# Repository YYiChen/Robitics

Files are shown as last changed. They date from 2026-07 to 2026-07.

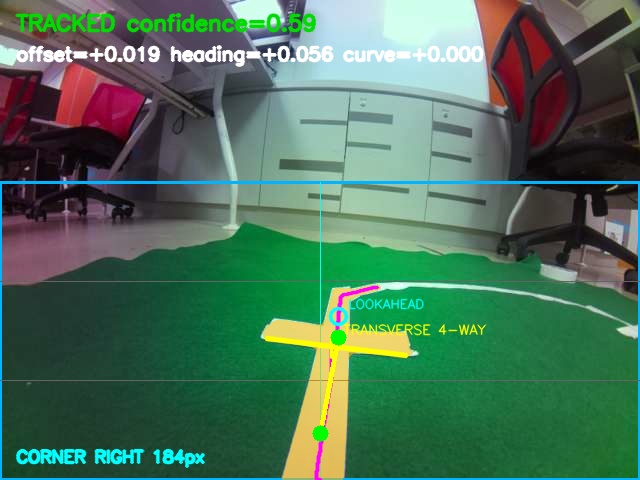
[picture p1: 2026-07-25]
artifacts/green_white_transverse_debug.jpg

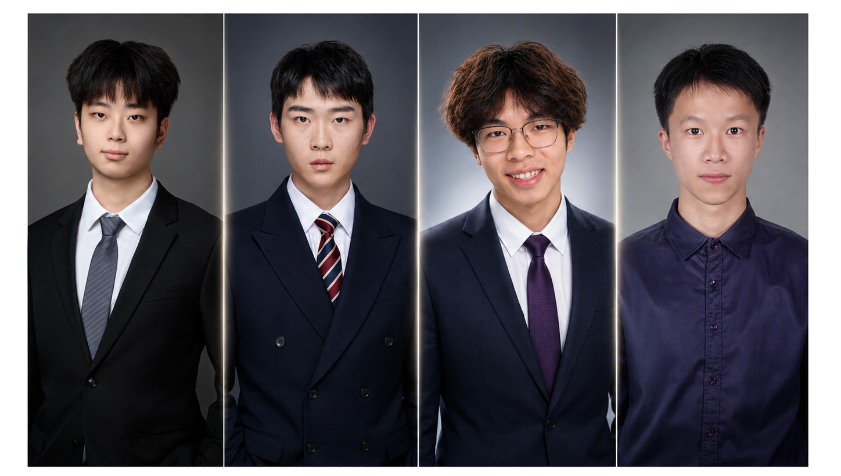
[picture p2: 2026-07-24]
assets/project_images/专业团队.png

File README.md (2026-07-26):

# Robitics

正式控制链路：浏览器 → 树莓派网页服务 → USB 串口 → Arduino Mega。

- Arduino 在 `firmware/motor_bridge/` 中执行电机输出、后轮编码器 PID、1 秒心跳停车、MPU-6500 遥测和一个前向超声波测距。
- 树莓派服务在 `pi_service/` 中执行串口协议转换、CSI 视频和网页 API。
- 浏览器仅显示/控制；图片保存是可选的本机功能，绝不写入树莓派。

## 项目结构

日常部署只需要关注下列正式主线；完整边界见 [docs/architecture.md](docs/architecture.md)。

给同事交接时，请先阅读 [docs/TEAM_HANDOVER.md](docs/TEAM_HANDOVER.md)：它列出正式部署入口、全部小车相关页面、验证页面边界、配置文件和资料归档位置。

```text
firmware/motor_bridge/     正式 Arduino Mega 固件（唯一日常烧录目标）
pi_service/robot_web/      正式树莓派网页、相机和串口服务
pi_service/tests/          正式服务回归测试
docs/                      协议与架构文档
tools/windows_recorder/    Windows 端 MJPEG 图片记录工具
```

`firmware/experiments/` 与 `pi_service/experiments/` 仅用于硬件或算法验证，不能替代正式部署。`archive/` 保存历史资料、快照和采集证据；`hardware/cad/` 保存机械设计；`deskmate/` 和 `third_party/` 是独立 Git 项目。

## 部署

1. 用 Arduino IDE 打开并烧录 `firmware/motor_bridge/motor_bridge_1_/motor_bridge_1_.ino`。该目录中的两个 `.h` 文件必须与草图保留在同一目录。
2. 将 `pi_service/` 复制到树莓派，执行 `./install_dependencies.sh` 一次。
3. 执行 `chmod +x start_robot.sh && ./start_robot.sh`，随后打开输出的网址。脚本使用 Bash，不能用 `sh start_robot.sh` 启动。

`start_robot.sh` 是日常正式入口：`camera.py` 同时配置 CSI 主画面与 640×480 lores 输出，低延迟 MJPEG 直接读取 lores。高清 JPEG 默认 `2 FPS / 质量 75`，可在网页调为 `1–15 FPS`；关闭高清预览时不持续编码该通道。

当前默认路线模式为 `pc_vision_adaptor`：树莓派只做底部近场白胶带跟随、网页预览、M 键门控和唯一的 M1/M2 PWM 输出；电脑端通过 `/api/vision-adaptor/frame` 拉取最新 JPEG，在本机运行绿地、红标、骨架和路口等重型识别，并仅向 `/api/vision-adaptor/event` 回传带帧号、时间和 token 的高层视觉事件。电脑端不能调用 PWM，也不能绕过 M 键。协议、电脑端启动命令、失联安全策略和测试见 [pc_vision_adaptor_validation](pi_service/experiments/pc_vision_adaptor_validation/README.md)。

## 低延迟 H.264 / WebRTC 视频

默认 `start_robot.sh` 仍是 MJPEG 兼容模式。需要低延迟连续视频时，使用 H.264/WebRTC：CSI 由 `rpicam-vid` 独占并以 H.264 编码，MediaMTX 分发 WebRTC 给网页、RTSP 给电脑 DL；Flask 只保留控制、串口和状态 API。

```bash
cd ~/Desktop/Robitics/pi_service
chmod +x install_webrtc.sh start_webrtc.sh
./install_webrtc.sh        # 一次性下载匹配系统架构的 MediaMTX
./start_webrtc.sh
```

默认采用单 CSI 相机双输出：`1640×1232` 主画面每秒编码 2 张 JPEG 75，`640×480 / 30 FPS / 1.5 Mbps` 低分辨率画面编码为 H.264/WebRTC。实时 H.264 使用 Baseline、每 8 帧一个关键帧（30 FPS 时约 267 ms）和立即刷包的 MPEG-TS 输出，以缩短固定缓冲。网页仍访问 `http://树莓派IP:5000`，左侧为 `http://树莓派IP:8889/cam/` 的 WebRTC 预览，右侧为高清 JPEG；电脑端 DL 可读取 `rtsp://树莓派IP:8554/cam`。按 `Ctrl+C` 会停止 Flask、Picamera2 双输出和 MediaMTX。日志保存在 `pi_service/logs/`。

服务启动约 3 秒后，执行自动验收：

```bash
chmod +x verify_webrtc.sh
./verify_webrtc.sh
```

它必须输出 `Flask backend: webrtc`、高清 JPEG 目标与 `PASS`。若 `Camera online: False`，先查看 `logs/mediamtx.log` 和运行 `start_webrtc.sh` 的终端输出；若命令通过但电脑无法播放，检查热点网络是否允许树莓派的 TCP 8889 和 WebRTC UDP 通信。

可在启动前调节参数，例如：

```bash
ROBOT_WEBRTC_WIDTH=640 ROBOT_WEBRTC_HEIGHT=480 ROBOT_WEBRTC_BITRATE=1500000 ROBOT_WEBRTC_GOP_FRAMES=8 \
ROBOT_HIGHRES_WIDTH=1640 ROBOT_HIGHRES_HEIGHT=1232 ./start_webrtc.sh
```

WebRTC 模式不能同时运行 `start_robot.sh`，也不会支持现有 MJPEG 的浏览器 Canvas 裁切、浏览器 JPG 保存或网页 EV/快门动态调节；这些功能仍可通过 `start_robot.sh` 使用。WebRTC 页面与 RTSP 使用同一条低分辨率 H.264 流；高清 JPEG 通过 `/highres_feed` 和 `/api/camera/highres/latest` 独立提供，浏览器与 DL 可各自使用该接口，但每增加一个客户端都会增加该 JPEG 通道的网络流量。

## 重要约定

- 串口波特率为 9600；协议见 `docs/serial-protocol.md`。
- 电机分配为 M1 右侧行驶、M2 左侧行驶、M3 送牌、M4 出牌。M3/M4 上电后默认关闭；网页可分别实时设置 PWM（1–255）、正转/反转和运行时间（0.1–60 秒），无需为这些参数重复烧录。默认值为 M3 反转 255/5 秒、M4 正转 255/1 秒。网页保持 `W/A/S/D` 行驶控制；单击键盘 `P` 会通过同一按键控制通道同时按各自预设触发 M3 和 M4，并分别等待 Arduino 确认。
- 后轮编码器使用 Mega 的 18（左）和 19（右）；IMU 使用 MPU-6500 I2C。
- 超声波仅保留中间前向传感器（TRIG 26 / ECHO 27），返回 `US,front`；当前阈值为 1 cm，达到阈值时 Arduino 只拒绝前进，原地转向和后退不受限制。
- SG90 舵机信号线使用 Mega D23，网页滑块控制 `0–180°`；Mega D22 保留给 HW-487 卡片光电传感器。舵机必须独立稳定供电并与 Mega 共地。舵机命令不会延长电机心跳。
- 网页“轮速配置”、PWM 与 PID 参数保存在树莓派独立的 `drive_config.json`；该文件不进入 Git，也不会被后续代码更新覆盖。首次升级会从旧 `robot_config.json` 自动复制现有调参值。`drive_config.example.json` 仅是可提交的默认模板。
- 网页相机支持自动曝光 EV 和固定快门；快门以 `1/xx` 秒输入。自动曝光模式下 EV 生效，固定快门模式下关闭自动曝光。
- 日常网页预览的“低延迟”档位为 `640×480`、JPEG 质量 60，直接使用相机 lores 输出。高清 JPEG 通道默认 `2 FPS`、质量 75，可在网页调为 `1–15 FPS`，不在树莓派保存文件；DL 或电脑可用 `/highres_feed` 获取连续图片，或用 `/api/camera/highres/latest` 拉取最新单张。高清通道可在网页选择原始尺寸、最大 1640 px 或最大 1280 px，切换不重启相机。
- 网页采用“按住才动、松开即停”的按键状态协议：浏览器每 180 ms 经 HTTP/TCP 发送按键集合，树莓派每 200 ms 向 Arduino 发送电机命令。网页失焦、网络断开和 Arduino 1 秒收不到命令都会停车。
- 摄像头云台舵机由 Arduino 每 20 ms 平滑更新；网页 Q/E 只保持左/右方向心跳，断开后 Arduino 会平滑减速停止。网页的“Q/E 速度”是最大角速度，默认加速度为 `120 °/s²`。
- `Z` 或“摄像头回正”使用独立快速回正命令，直接以舵机自身的机械最大速度回到网页配置的中位角度；它不会受 Q/E 速度限制。
- Arduino 每 200 ms 回传一次实际云台角度；网页会用该读数校正云台图示，并在两次读数之间平滑动画。
- 网页 CSI 视频卡片会显示实时分辨率、采集/发送 FPS、JPEG 单帧大小、编码耗时、最新帧延迟以及 MJPEG 实际发送带宽；带宽同时显示十进制 `kB/s` 和 `kbps`。
- 网页“传输档位”与“相机读取档位”分开：相机仍以选择的 CSI 分辨率和 30 FPS 采集，树莓派只将缩放后的 JPEG 最新帧发给网页。默认“低延迟”为 `640×480`、JPEG 质量 60，显著降低热点带宽且不新增队列/缓存；需要高清图片时使用独立的 2 FPS 高清 JPEG 通道。上述档位会保存到 `camera_config.json`。
- 默认网页视频仍是低延迟 MJPEG；通过 `start_webrtc.sh` 可切换至 H.264/WebRTC 独立媒体服务，不能与 MJPEG 模式同时启动。
- 视频卡片中的“电脑端辅助画面”使用浏览器 Canvas 复用当前视频帧，可完整缩放或中心裁切到 640×480；它不创建第二条视频连接，不增加树莓派网络带宽和编码负载。
- 网页可在 `1640×1232` 与 `3280×2464` 两个 CSI 读取档位之间切换；两个档位都请求 30 FPS 传感器帧时长，切换会短暂重启视频流，实际采集/编码帧率以网页指标为准。
- 本地图片保存需要 Chrome/Edge 的 HTTPS 或 localhost 安全上下文，并由用户选择文件夹授权。
- OLED 为可选的 SSD1306 `64×48` I2C 模块：GND→pin 6、VCC→pin 1（3.3V，推荐）或 pin 2（5V）、SDA→GPIO2/pin 3、SCL→GPIO3/pin 5；先用 `sudo raspi-config` 开启 I2C。默认地址为 `0x3C`、总线 1，服务启动后每秒显示 Arduino、相机和前向距离。OLED 缺失、I2C 未开或依赖未装不会阻止控制服务启动，网页“状态”标签会显示错误原因。可用 `--disable-oled` 关闭，或以 `--oled-address 0x3D --oled-i2c-port 1` 修改参数。

## Git 工作流

`main` 是唯一可部署分支；`archive/*` 仅保留旧版本。每次完成真实硬件验证后创建本地标签，例如 `robot-v0.1.0-verified`。

## Windows 本地 JPG 保存（5 FPS）

在 Windows PowerShell 中运行，替换为树莓派实际 IP：

```powershell
.\tools\windows_recorder\start_windows_recorder.ps1 -StreamUrl 'http://树莓派IP:5000/video_feed'
```

图片只会保存到 `data\captures\YYYY-MM-DD\`，不会上传或写回树莓派。按 `Ctrl+C` 停止；断线后每 3 秒自动重连，并在可用空间少于 5 GB 时安全停止。

浏览器内的“连续保存”也是 5 FPS，但需要 Chrome/Edge 的 HTTPS 或 localhost 文件夹授权；给队友使用时优先采用上述 Windows 记录器。

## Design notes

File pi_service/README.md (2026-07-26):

# Robitics Pi Service

`pi_service/` is the complete Raspberry Pi software subproject for the Robitics
vehicle. Its governance, maintenance rules, tests, experiments, and runtime
boundaries are local to this directory.

Read [AGENTS.md](AGENTS.md) before changing this subproject.

## Current Formal Runtime

The normal control chain is:

```text
start_robot.sh
  -> robot_web/app.py
  -> active route tracker
  -> robot_web/controller.py
  -> USB serial
  -> Arduino Mega
```

The current default route mode is `end_line_turn_adaptor`. The service starts
vision paused; the operator uses the port-5000 console to arm or stop motor
control. Source support, passing tests, and successful HTTP/serial replies must
not be reported as successful physical motion without a real-car check.

Normal Pi startup:

```bash
cd /home/g11/Desktop/pi_service
chmod +x start_robot.sh
./start_robot.sh
```

This command can access the camera and Arduino. Do not run it as part of an
ordinary documentation, cleanup, or unit-test task.

## Directory Contract

| Path | Status | Responsibility |
| --- | --- | --- |
| `robot_web/` | Production | Flask API, browser UI, camera, route adapters, controller, telemetry, and safety-facing control flow |
| `tests/` | Production regression | Tests for formal service contracts |
| `experiments/` | Isolated validation | Algorithm, perception, calibration, hardware, and operator trials |
| `start_robot.sh` | Formal entry | Normal MJPEG control service; default route is `end_line_turn_adaptor` |
| `start_webrtc.sh` | Optional entry | H.264/WebRTC transport; mutually exclusive with the MJPEG camera owner |
| `verify_webrtc.sh` | Validation | WebRTC service verification after startup |
| `run_*_console.sh` | Explicit route selection | Operator launchers for a named route or validation mode |
| `install_dependencies.sh` | Setup | Pi OS packages and Python dependencies |
| `install_webrtc.sh` | Setup | Local MediaMTX installation under ignored `vendor/` |
| `robot_client.py` | Support library | HTTP client used by isolated tools and tests |
| `logs/`, `run/`, `runtime_logs/` | Runtime only | Logs and transient evidence; never source |

Files should not be moved between these areas only to make the tree look
cleaner. A move must have a functional target, updated imports and launchers,
and matching validation.

## Formal Modules

The formal service is split into independently debuggable packages:

| Module | Responsibility |
| --- | --- |
| `app.py` | CLI, service assembly, lifecycle, and route-mode selection only |
| `api/` | Camera, control, route, and status HTTP endpoint registration |
| `controller.py` | Sole Pi-side Arduino serial and M1/M2 ownership facade |
| `control/` | Drive config, pure motor mapping, protocol parsing, servo, and card workflows |
| `camera.py` | MJPEG CSI hardware lifecycle |
| `dual_stream_camera.py` | WebRTC/H.264 plus high-resolution JPEG hardware lifecycle |
| `media/` | Camera profiles, settings persistence, colour correction, and transport metrics |
| `webrtc_stream.py` | WebRTC transport integration |
| `routes/common.py` | Shared motor run gate and latest-frame preview publisher |
| `routes/end_line/` | Current white-line/end-line perception, profiles, and tracker |
| `routes/scanline/` | Scanline models, config, control, perception, planning, logging, and variants |
| `routes/pc_adaptor/` | PC event protocol plus Pi-local fast perception and motor tracker |
| `routes/generic/` | Generic continuous-path planner, control, marker count, and tracker |
| top-level route shims | Compatibility imports for existing scripts; no implementation ownership |
| `templates/`, `static/` | Port-5000 browser console |

Only `controller.py` should translate a route decision into the formal serial
motor path. Experiments must not silently become competing camera or motor
owners.

## Debug Map

Use the smallest module matching the symptom:

| Symptom or adjustment | Start with | Hardware-free check |
| --- | --- | --- |
| Wrong wheel sign/PWM | `control/motor_commands.py` | `test_control_modules.py` |
| Arduino reply parsing | `control/protocol.py` | `test_control_modules.py` |
| M3/M4 sequence or validation | `control/card_control.py` | `test_controller_persistence.py` |
| Servo command/heartbeat | `control/servo_control.py` | `test_controller_persistence.py` |
| Camera profile persistence | `media/settings.py` | `test_media_modules.py` |
| Camera bandwidth numbers | `media/metrics.py` | `test_media_modules.py` |
| Edge colour correction | `media/color_correction.py` | `test_camera_metrics.py` |
| HTTP request/response | matching file in `api/` | `test_api_structure.py` |
| Current terminal detection | `routes/end_line/perception.py` | end-line experiment tests |
| Current turn state/thread loop | `routes/end_line/tracker.py` | adaptor tuning tests |
| Scanline thresholds | `routes/scanline/config.py` | `test_scanline_modules.py` |
| Scanline wheel correction | `routes/scanline/control.py` | `test_scanline_modules.py` |
| Scanline evidence/state types | `routes/scanline/models.py` | scanline route tests |
| Scanline visual detection | `routes/scanline/perception.py` | scanline route tests |
| Scanline turn state machine | `routes/scanline/planner.py` | scanline route tests |
| Scanline audit records | `routes/scanline/logging.py` | scanline route tests |

Static path validation, which does not open hardware:

```bash
python3 pi_service/verify_paths.py
```

## Experiments

`experiments/` is grouped conceptually rather than by execution priority:

- drive and mapping: `car_drive_test`, `constant_drive_90_validation`,
  `differential_drive_mapping_validation`;
- route and line behavior: `continuous_path_validation`,
  `fixed_rectangle_validation`, `line_tracking_validation`,
  `straight_line_stop_validation`, and the `i_shape_*` families;
- terminal and marker perception: `end_line_turn_validation`,
  `marker_count_preview_validation`, `red_marker_feature_validation`;
- PC/Pi vision adapters: `pc_vision_adaptor_validation`,
  `fixed_course_offline_validation`;
- face tracking and motor sandboxes: `face_tracking_validation`,
  `pc_face_*`, `phone_face_*`;
- incomplete placeholders must remain visibly experimental until they gain an
  entry command, README, deterministic validation, and an explicit owner.

Each experiment owns its local files and README. Do not read or modify unrelated
experiments during a bounded target.

Promotion from an experiment to `robot_web/` requires:

1. a defined production responsibility;
2. deterministic focused tests;
3. integration tests under `tests/`;
4. preserved stop/timeout behavior;
5. documentation of Pi and physical-car validation;
6. removal or clear supersession of duplicate control ownership.

## Maintenance Workflow

For every target:

1. State the goal, owned files, read-only dependencies, validation, and hardware
   boundary in the task conversation.
2. Inspect `git status` and only the relevant production module or experiment.
3. Make one bounded class of change: feature, fix, tuning, cleanup, or move.
4. Run focused deterministic checks.
5. Review `git diff --check -- pi_service` and the owned diff.
6. Commit only the intended `pi_service` paths. Deployment and physical tests
   remain separate steps.

No repository-level `plan/` directory is required for this subproject. The
bounded target is recorded in the task conversation, the validation result in
the handoff, and the durable implementation state in Git.

## Validation Commands

From the repository root on Windows:

```powershell
py -3 -m unittest discover -s pi_service/tests -v
node --check pi_service/robot_web/static/app.js
git diff --check -- pi_service
git status --short --branch
```

Focused experiment:

```powershell
py -3 -m unittest discover -s pi_service/experiments/<target> -p "test_*.py" -v
```

On the Pi, validate a changed shell launcher before use:

```bash
bash -n pi_service/start_robot.sh
bash -n pi_service/<changed-launcher>.sh
```

Local tests may skip Flask, Picamera2, GPIO, I2C, serial, or MediaMTX behavior.
Report those as environment gaps. Never convert a skipped check into a claim of
Pi or vehicle validation.

## Configuration and Runtime Data

Formal runtime configuration now has one sectioned contract:

- `config/defaults.json` is the tracked shape and safe source default;
- `config/local.json` is the ignored Pi-specific override and the only file
  written by the formal web service;
- `config/local.example.json` shows the override structure without carrying
  deployed tuning;
- the owned sections are `drive`, `camera`, and `routes.end_line`.

On startup, the formal service imports existing values from
`robot_web/drive_config.json`, legacy `robot_web/robot_config.json`,
`robot_web/camera_config.json`, and the current end-line tuning/profile JSON
files only when the matching section is absent from `config/local.json`.
Existing unified sections always win. Keep those legacy files during the first
Pi rollout and compare the generated local override before retiring them.

Configuration precedence is:

1. an explicit CLI option such as `--drive-config`;
2. `config/local.json`;
3. `config/defaults.json`;
4. in-code validation defaults for missing or invalid fields.

Other deployment-specific state includes:

- `logs/`, `run/`, and all experiment `runtime_logs/`;
- downloaded `vendor/` contents.

The `routes.end_line` web panel also owns the shared J/L/H/K visual-turn
settings: pulse PWM, pulse duration, stopped interval, search timeout, and the
white-line centre deadband/confirmation count.  J/L face centring and H/K
white-line centring use the same pulse settings; Q/E/U/I keep their independent
red-line preset profiles.

Never put credentials in either configuration file. Preserve
`config/local.json` during code synchronization; copying tracked source files
must not replace a tuned vehicle.

## DeskMate Robotics API

The versioned `/api/robotics/v1/*` facade is the supported server-to-server
boundary for DeskMate.  It wraps, but does not replace, the existing browser
endpoints:

- `GET capabilities`, `GET status` and `GET config` are read-only;
- `POST gate` sets the motor gate explicitly with `{"enabled": true|false}`;
- `POST actions` accepts idempotent semantic requests for line following,
  face-turn start/heartbeat/stop, white-line recentering, preset 90/180-degree
  turns, one-card mechanism requests and stop;
- `POST config` updates only the grouped line-follow and visual-turn settings
  already owned by `routes.end_line`.

Every action requires a caller-generated URL-safe `request_id` (letters,
digits, dot, underscore, colon or hyphen). Reusing an ID with a different
payload is rejected.  An HTTP retry for one event reuses its ID;
successive face-heartbeat events need distinct IDs so the Pi dead-man timer is
refreshed.  `dispense_one` reuses the controller's tokenized workflow so
polling/retry only reads the current result and cannot issue another motor
request.  Its completion evidence is explicitly `arduino_command_ack_only`;
current hardware
does not provide the deck-present, exit-pulse, interlock or E-stop evidence
required to report a successful DeskMate `DealerAck`.

If an action response is lost or the client times out, do not submit a new
action ID. Query `GET /api/robotics/v1/requests/<request_id>` first. A known ID
returns the correlated request result without restarting the motion; an unknown
ID returns HTTP 404. Each result includes `request_status` (`running`,
`succeeded`, `failed`, or `cancelled`) and `terminal`. Terminal results also
include `completed_at`. A later semantic stop records
`completed_by_request_id` on the request it completed or cancelled. The raw
route/controller state remains available in `state` and `detail`.

The bounded idempotency/result cache belongs to the current service process, so
callers must treat a Pi service restart as a new control epoch and reconcile
through `GET /api/robotics/v1/status`.

The browser telemetry loops are single-flight: a slow status or face request
must finish or time out before its successor is scheduled. Control heartbeats
also permit at most one in-flight request. This prevents a temporary network
delay from becoming a backlog that starves later STOP or manual-control calls.

Runtime logs are useful evidence but are not source code. Move selected evidence
into a deliberately named artifact or report only when a target explicitly
requires durable evidence.

## Git and Deployment Boundary

- Keep unrelated repository paths outside a `pi_service` change.
- Keep unfinished experiments off the deployable mainline until reviewed.
- Do not force-push shared history.
- Do not commit credentials or local authentication helpers.
- Synchronizing files to the Pi does not authorize service startup, firmware
  flashing, autonomous driving, or any motor action.

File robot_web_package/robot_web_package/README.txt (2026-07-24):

Loss Hunters 树莓派小车网页控制包
=================================

目标
----
只启动一个 Python 程序，然后在同一个网页完成：
- CSI 摄像头视频流
- W/A/S/D、方向键和 Q/E/Z/C 控制
- 松开按键自动停车
- 空格/网页按钮紧急停止
- PWM、速度模式、目标速度和 PID 参数调整
- Arduino/摄像头在线状态
- IMU 与轮速数据显示
- 拍摄当前画面

默认网页
--------
http://100.80.46.54:5000/

首次部署
--------
1. 把整个文件夹复制到树莓派，例如：
   /home/g11/robot_web/

2. 进入文件夹并赋予执行权限：
   cd /home/g11/robot_web
   chmod +x *.sh

3. 缺少依赖时只执行一次：
   ./install_dependencies.sh

一键启动
--------
./start_robot.sh

之后直接打开：
http://100.80.46.54:5000/

停止
----
./stop_robot.sh

开机自动启动（可选，只安装一次）
--------------------------------
./install_autostart.sh

之后树莓派开机即可直接访问网页，不需要打开 VS Code。

常见调整
--------
Arduino 不是 /dev/ttyACM0 时：
ROBOT_SERIAL_PORT=/dev/ttyACM1 ./start_robot.sh

也可以让程序自动搜索：
ROBOT_SERIAL_PORT=auto ./start_robot.sh

更换网页端口：
ROBOT_WEB_PORT=5001 ./start_robot.sh

日志位置：
logs/robot.log

重要安全机制
------------
网页每 180 ms 发送一次心跳；超过 0.8 秒没有心跳，树莓派自动清空运动指令。
网页失焦、切换标签页、松开按钮或网络断开时会停车。
程序正常退出时会重复发送停车命令。

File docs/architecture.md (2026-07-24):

# Robitics architecture

## Deployment boundary

The deployed robot is deliberately small:

```text
Browser -> pi_service/robot_web -> USB serial -> firmware/motor_bridge -> hardware
                 |                                  |
                 +-> CSI camera / MJPEG or WebRTC    +-> drive, card motors, PID, sensors
```

`pi_service/start_robot.sh` is the normal MJPEG entry point. `start_webrtc.sh` is an alternative video transport, not a second service to run at the same time. The browser owns manual key state; `controller.py` owns serial translation and watchdog heartbeats; the Arduino owns raw motor output, encoder PID, servo smoothing and forward-obstacle blocking.

## Canonical directories

| Path | Role | Deployment status |
| --- | --- | --- |
| `firmware/motor_bridge/` | Arduino Mega production firmware and flash helper | Formal firmware |
| `pi_service/robot_web/` | Flask UI, serial controller, CSI camera, OLED and WebRTC adapter | Formal Pi service |
| `pi_service/tests/` | Service regression tests | Formal verification |
| `docs/` | Serial protocol, architecture and team material | Documentation |
| `tools/windows_recorder/` | Optional Windows-side MJPEG recorder | Optional workstation tool |
| `firmware/experiments/` | Isolated motor/card hardware sketches | Never flash as the default firmware |
| `pi_service/experiments/` | Isolated car-drive and line-tracking validations | Not connected to automatic motion |
| `third_party/` | Independently versioned external source references | Not deployed directly |
| `hardware/cad/` | CAD, STL and assembly assets | Mechanical reference |
| `archive/` | Course material, legacy controls, snapshots, release artifacts and capture evidence | Historical reference |

## Motor ownership

The current production firmware assigns M1 to right drive, M2 to left drive, M3 to timed card feeding and M4 to timed card dealing. The formal firmware is the only place where that contract should change. Older sketches may use different assignments and are therefore under `firmware/experiments/` or `archive/`.

## Line-tracking boundary

`pi_service/experiments/line_tracking_validation/` is a pure-Python state-machine experiment. It has no camera, GPIO, serial or motor I/O. The external OpenCV detector under `third_party/DeskMate-Advance/src/track_line/` is perception-only. A future live line-following feature must add a vision adapter, route/state planner and an explicit auto/manual safety arbiter before it can send actions through `controller.py`.

## Git boundary

The root repository owns the Robitics source, documentation, mechanical assets and archive. `deskmate/` and `third_party/DeskMate-Advance/` are independent repositories with their own histories; do not add them as embedded Git directories or deploy them as part of the Pi service.

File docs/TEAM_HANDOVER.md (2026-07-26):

# Robitics 同事交接索引

本仓库的正式控制链路是：**浏览器 → 树莓派网页服务 → USB 串口 → Arduino Mega**。日常使用只从本页列出的“正式入口”开始；`experiments/` 中的内容用于单项验证，不能当作完整小车程序部署。

## 1. 交接时需要的目录

| 目录 | 用途 | 是否需要部署到树莓派 |
| --- | --- | --- |
| `firmware/motor_bridge/motor_bridge_1_/` | Arduino Mega 正式固件：M1/M2 行驶、M3/M4 发牌、云台、编码器 PID、IMU、超声波安全与串口协议 | 需要烧录到 Mega |
| `pi_service/robot_web/` | 正式 Flask 控制台、相机、串口控制、自动路线适配器和网页静态资源 | 需要 |
| `pi_service/start_robot.sh` | MJPEG 日常启动入口（默认端口 5000） | 需要 |
| `pi_service/install_dependencies.sh` | Pi 上的一次性依赖安装 | 需要 |
| `pi_service/start_webrtc.sh`、`install_webrtc.sh` | 可选 H.264/WebRTC 启动方式；不能和 `start_robot.sh` 同时运行 | 按需 |
| `docs/` | 协议、架构和本交接索引 | 建议一并保留 |
| `tools/windows_recorder/` | Windows 电脑端录像/逐帧 JPG 保存工具 | 仅 Windows 电脑 |

部署时将整个 `pi_service/` 复制到树莓派；不要只复制 `robot_web/`，因为启动脚本、依赖脚本、测试和实验说明都在其上层目录。

## 2. 所有小车相关网页/页面

### 正式日常控制台

- 页面源码：`pi_service/robot_web/templates/index.html`
- 前端逻辑：`pi_service/robot_web/static/app.js`
- 样式：`pi_service/robot_web/static/style.css`
- 后端入口：`pi_service/robot_web/app.py`
- 启动：在 Pi 的 `pi_service/` 目录执行 `chmod +x start_robot.sh && ./start_robot.sh`，浏览器打开 `http://<Pi-IP>:5000`。

控制台包含三组页面标签：

1. **相机**：低延迟 MJPEG、路线预判、按需高清 JPEG、曝光/传输档位与电脑端本地保存。
2. **行驶控制**：M1/M2 PWM、速度 PID、摄像头云台、M3 送牌/M4 出牌、W/A/S/D/Q/E/Z/P 等实时控制。
3. **系统状态**：Arduino、IMU、轮速、实际 M1/M2 PWM、相机指标、CPU/温度/OLED 状态。

安全规则：网页按键松开、失焦或断网会停车；树莓派心跳停止和 Arduino 一秒未收到指令也会停车。自动路线必须先按 **M** 解锁，且只允许主服务控制 M1/M2。

### 验证页面（保留，不作为正式交付入口）

| 页面/实验 | 路径 | 用途与边界 |
| --- | --- | --- |
| 小车整车测试 | `pi_service/experiments/car_drive_test/templates/index.html` | M1/M2 方向和 PWM 的单项检查；不能与正式控制台同时控制电机。 |
| 路线验证页面 | `pi_service/experiments/*/debug_web.py` | 直线、矩形、I 型、扫描线、终点转向等视觉/路线验证。先阅读各目录 `README.md`。 |
| 人脸跟踪服务 | `pi_service/experiments/face_tracking_validation/` | 独立相机/人脸识别验证，非小车主控功能。 |

## 3. 固件与电机对应关系

- `M1`：右侧行驶电机；`M2`：左侧行驶电机。
- `M3`：送牌；`M4`：出牌。
- 正式草图是 `motor_bridge_1_.ino`，同目录 `motor_control.h` 和 `ultrasonic_avoidance.h` 必须一起保留。
- 协议与命令说明见 [serial-protocol.md](serial-protocol.md)。Pi 端一键烧录工具见 `firmware/motor_bridge/motor_bridge_1_/pi_flash/`。

## 4. 配置与不可提交文件

Pi 上调出的真实参数会保存在以下本机文件，Git 特意忽略它们；交接时如需复用已调好的数值，请通过安全渠道单独复制，不能把其中的设备信息或密码推送到 GitHub：

- `pi_service/robot_web/drive_config.json`
- `pi_service/robot_web/camera_config.json`
- `pi_service/robot_web/robot_config.json`

可提交的默认参考是 `drive_config.example.json`。同事第一次部署前应先确认串口设备、CSI 相机和 Arduino 实际接线。

## 5. 资料归档与仓库边界

- `hardware/cad/`：机械 CAD、STL、装配体；只做建模/打印时使用。
- `archive/`：课程材料、旧控制程序、旧发布包和采集证据；保留可追溯性，不参与日常部署。
- `artifacts/`：离线验证产物。
- `deskmate/` 和 `third_party/`：**独立 Git 仓库**，不属于 Robitics 主仓库推送范围，也不应复制进本项目历史。

## 6. 推送前检查

```bash
git status -sb
git diff --check
python3 -m unittest discover -s pi_service/tests -v
```

推送前确认没有 `drive_config.json`、`camera_config.json`、日志、录像、账号令牌或私钥被暂存。当前 GitHub 主仓库：<https://github.com/YYiChen/Robitics>。

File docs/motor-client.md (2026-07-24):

# Pi Service 通用电机调用

`pi_service/robot_web` 是唯一能直接打开 Arduino 串口的服务。其他程序禁止各自
创建 `RobotController` 或直接操作串口；统一调用 `pi_service.robot_client`。

```python
from pi_service.robot_client import RobotClientConfig, RobotWebClient

robot = RobotWebClient(RobotClientConfig("http://127.0.0.1:5000"))
robot.require_arduino_online()
robot.send_action("F")   # F / FL / FR / PL / PR / STOP 等
# 程序结束或异常时必须执行：
robot.stop()
```

远程电脑控制 Pi 时，将地址替换为 Pi 的地址，例如
`http://100.80.46.54:5000`。

## 配置行驶 PWM

通过同一个客户端调用 `configure_drive()`，配置会交给 robot-web 校验并保存到
Pi 的 `drive_config.json`。不要绕开 API 直接改运行中的控制状态。

```python
robot.configure_drive({
    "speed_mode": False,
    "straight_pwm": 120,
    "pivot_pwm": 150,
})
```

浏览器遥控与自动程序会共享同一个动作状态；自动运行时不要按网页 WASD/方向键，
否则网页的心跳会覆盖自动程序的动作。控制循环异常、视觉丢失或任务结束时应发送
`STOP`。

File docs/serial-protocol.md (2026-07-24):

# Arduino 串口协议

所有命令均以换行结束，波特率为 9600。

| 命令 | 说明 |
| --- | --- |
| `M,m1,m2,m3,m4` | 行驶 PWM（-255..255）；M1 为右侧、M2 为左侧，M3/M4 字段被忽略 |
| `FEED,pwm,timeMs` | 触发一次 M3 送牌；`pwm` 为 1–255，`timeMs` 为 100–60000，方向固定为已验证的反向；运行期间重复命令返回 `BUSY:FEED` |
| `DEAL,pwm,timeMs` | 触发一次 M4 出牌；`pwm` 为 1–255，`timeMs` 为 100–60000，方向固定为已验证的反向；运行期间重复命令返回 `BUSY:DEAL` |
| `V,leftPPS,rightPPS` | M2/M1 左右行驶电机 PID 的目标脉冲每秒 |
| `KP,value` / `KI,value` / `KD,value` | 后轮 PID 参数 |
| `STOP` | 立即停止 M1/M2 行驶并退出速度模式；不打断已经触发的 M3/M4 本地定时周期 |
| `IMU` | 返回 `IMU,roll,pitch,yaw`；仅遥测 |
| `SPD` | 返回 `SPD,curL,curR,tgtL,tgtR,pidL,pidR` |
| `US` | 返回 `US,front`；当前只接中间前向超声波（26/27） |
| `SV,angle` | 设置 SG90 舵机角度（0–180），信号线为 Mega D23；不会刷新电机心跳 |

电机固定分配：M1 为右侧行驶、M2 为左侧行驶、M3 为送牌、M4 为出牌。M3/M4 上电默认关闭，均由 Arduino 本地非阻塞定时，网页断线也会按请求时间停止。为兼容旧调用，省略参数的 `FEED` 和 `DEAL` 分别使用 255/5000 ms 和 255/1000 ms。

Arduino 保留最终行驶安全权：1 秒未收到有效行驶命令时停止 M1/M2。前方距离达到配置阈值时只拒绝前进；原地左转、原地右转和后退不受超声波限制。`-1` 代表无有效超声波回波，不代表障碍物。

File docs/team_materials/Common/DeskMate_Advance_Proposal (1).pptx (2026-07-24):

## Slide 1

DeskMate

Team 11 — Loss Hunters

Wang Tianqi · Chen Zengchun · Gu Songtao · Lin Ziqi

SWS3009 · ADVANCE PROPOSAL

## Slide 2

DESKMATE

GROUP 11 · LOSS HUNTERS

A MOVING DESKTOP COMPANION FOR FOCUS, WELL-BEING AND INTERACTION

ADVANCED PROJECT

DESKMATE

Vision · deep learning · autonomous robotics

Gu Songtao · Chen Zengchun

Loss Hunters · Group 11

PRODUCT VISION

A desktop companion that sees context

and responds through motion and expression

Students and office workers

who stay at a desk for long periods

TARGET USERS

DESKTOP COMPANION

CORE PROBLEM

Important habits are easy to miss

when reminders are passive or easy to dismiss

COURSE FIT

and fun enough to stay present on the desk

DESIGN PRINCIPLE

10 DAYS

Proactive, responsive

Deep-learning perception + autonomous robot control

Video + computer audio · moving parts · deep-learning automation · interactive feedback

Wang Tianqi · Lin Ziqi

01

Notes: The Advanced Model is optional and is introduced only when the Basic Model cannot classify continuous behaviour reliably. Candidate extensions include temporal posture classification, dynamic gesture recognition, phone-detector fine-tuning, multimodal off-task behaviour classification, noise-type recognition, and personalization. The recommended extension is a small TCN or GRU trained on normalized hand-landmark sequences with dimensions T by twenty-one by three. This input is compact, reduces background interference, and avoids training directly on raw video.

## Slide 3

PRODUCT OVERVIEW

HEALTH · FOCUS · COMPANIONSHIP

FROM PASSIVE REMINDERS TO A COMPANION THAT PERCEIVES AND ACTS

PRODUCT PROMISE

AWARE OF

Perceive → decide → move and respond

Reduce unnoticed long sitting

Interrupt harmful focus patterns

Make reminders visible and engaging

LONG SITTING

Detect prolonged seated or static states

then trigger a stretch or movement cue

Estimate face-to-screen distance

and sustained head / gaze direction

SCREEN & EYE USE

DESK CONTEXT

PHONE DISTRACTION

Detect persistent phone use

during an active focus session

DESKMATE RESPONSE

to mute, ignore, or forget

PASSIVE SOFTWARE

PROACTIVE

Notifications are easy

One event layer coordinates movement, display, servo and computer sound

The robot changes position or expression so the reminder becomes a physical interaction

02

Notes: The Advanced Model is optional and is introduced only when the Basic Model cannot classify continuous behaviour reliably. Candidate extensions include temporal posture classification, dynamic gesture recognition, phone-detector fine-tuning, multimodal off-task behaviour classification, noise-type recognition, and personalization. The recommended extension is a small TCN or GRU trained on normalized hand-landmark sequences with dimensions T by twenty-one by three. This input is compact, reduces background interference, and avoids training directly on raw video.

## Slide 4

CORE EXPERIENCE

PERCEIVE

Camera observes posture,

face, hands and phone

INTERPRET

Pre-trained models convert

frames into useful features

Temporal logic checks that

the behaviour persists

RESPOND

Robot moves, turns, displays

and plays sound through the laptop

RESET

User gesture or cooldown

returns to monitoring

CONFIRM

Start, pause and reset a focus timer

Detect persistent phone distraction

Celebrate completion with motion / display

FOCUS SUPPORT

Track sitting and static duration

Estimate screen distance and head direction

Prompt short breaks and posture changes

WELL-BEING CUES

Face recognition can personalize greetings

Screen shows emoji, status and timer

Movement makes the response visible and playful

COMPANION FEEDBACK

Video and laptop audio drive decisions; motion, display and sound close the interaction loop.

ONE LOOP, MULTIPLE MODALITIES

03

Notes: Frame-level predictions must be stabilized before they trigger a reminder. Moving averages, exponential smoothing, or majority voting reduce jitter, while duration and entry-exit thresholds prevent brief or oscillating states from generating events. Phone confidence, head direction, and system events can be fused, and gestures require confirmation across multiple frames. Low-confidence decisions return unknown, reminders use cooldown periods, and all thresholds remain adjustable through user testing.

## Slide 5

SYSTEM ARCHITECTURE

CAMERA / LAPTOP MIC

Video + computer audio

PI 5 OR LAPTOP

Perception and event logic

UNIFIED EVENTS

Confidence + duration gates

ARDUINO MEGA

Motor / servo control

ROBOT RESPONSE

Move, display, computer sound

PERCEPTION / DECISION

Vision models

Pose, face, hand and phone

ROLE

Two-wheel + caster and a mechanical arm remain optional mechanical extensions

CONTROL / FEEDBACK

Drive base

4 TT motors + HW-130 driver

ROLE

events

motion

Temporal logic

Interaction

Smooth, confirm and apply cooldown

gate

64×48 display + two servos

Safety sensors

Ultrasonic + tracking modules

feedback

Runtime choice

Raspberry Pi 5 or laptop

deploy

safety

Communication

USB serial JSON messages

serial

Scope boundary

04

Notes: The baseline validates the complete sensing-to-robot pipeline without training a task-specific model. Webcam frames and microphone signals are processed with OpenCV, timers, signal statistics, and hand-crafted thresholds, then converted into binary events. The supported functions include sitting duration, static posture, approximate screen distance, brightness, noise, simple gestures, and timer events. Phone classification, user identity, and complex dynamic gestures remain outside the baseline.

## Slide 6

DEEP LEARNING CORE

LAYER 01

PRE-TRAINED

PERCEPTION

PRE-TRAINED MODELS · EDGE / PC

MediaPipe Pose

POSE

MediaPipe Face

FACE / EYE

MediaPipe / cvzone

HAND

Object Detector +

EfficientDet-Lite0

PHONE

Optional YuNet +

SFace embedding

IDENTITY*

Landmarker

Landmarker

21 landmarks

FEATURES

LAYER 02

DERIVED

Body landmarks

Shoulder / neck / trunk angles

POSTURE

Landmark displacement

Variance + static duration

MOTION

Eye landmarks + blendshape

Head pose + distance level

EYE / HEAD

Five-finger state

Direction, speed, trajectory

GESTURE

Phone box + confidence

Identity similarity (optional)

DETECTION

LAYER 03

TEMPORAL +

RULE LOGIC

MOVING AVERAGE

Smooth frame-level features

MULTI-FRAME VOTING

Confirm stable state decisions

DURATION THRESHOLD

Emit only persistent states

REMINDER COOLDOWN

Avoid repeated interruptions

SUPPORT

Brightness statistics

Audio level / SPL

Clock and reminders

Robot actuation

PROGRAM LOGIC

05

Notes: The Basic Model is the main project deliverable and uses lightweight pre-trained models without custom training. MediaPipe provides pose, face, and hand landmarks; EfficientDet-Lite0 detects phones; and YuNet with SFace supports local user recognition. These models produce posture angles, motion variation, blink and head-pose features, gesture trajectories, detection confidence, and face similarity. Moving averages, multi-frame voting, duration thresholds, and reminder cooldowns stabilize the results on a standard CPU.

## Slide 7

UNIFIED EVENT OUTPUT

RAW MODEL OUTPUTS

"suggested_action": "move_and_prompt"

STANDARDIZED EVENT

EVENT VOCABULARY

KEYPOINTS

Body · face · hand

{

bad_posture

static_too_long

DETECTION

Class · box · confidence

"event": "bad_posture",

"model_level": "basic",

screen_too_close

low_blink_rate

environment_too_bright

IDENTITY

"confidence": 0.91,

"duration_s": 38,

environment_too_dark

noise_too_high*

GESTURE

Embedding · similarity

"evidence": {

"neck_angle_deg": 24.6

phone_usage_detected

off_task_behaviour

user_recognized

Class · probability

},

unknown_user

gesture_detected

AUDIO / STATE

Laptop noise level · state probability

}

DL MODULE

UNIFIED EVENT

CONTROLLER

06

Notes: The models produce landmarks, bounding boxes, confidence scores, face embeddings, gesture probabilities, noise measurements, and frame-level state probabilities. The deep learning module does not control the robot directly. Instead, it emits a standardized event containing the event name, model level, confidence, duration, supporting evidence, and a suggested action. The controller then maps that event to a robot expression, sound, or movement.

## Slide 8

HARDWARE & CONTROL

Raspberry Pi 5 · high-level compute

Power bank for Raspberry Pi

HW-130 motor driver

exploratory configuration

Primary demo uses four-wheel differential drive

MG90S + MG90 servos

Speaker and microphone

Laptop audio supplies the second input modality

COMPUTE

MOTION

INTERACTION

Four TT geared motors

64×48 monochrome display

2

1

Laptop · optional model runtime

1

1

3

IMX219 camera · video input

2

2

4

Arduino Mega 2560

motor + servo controller

3

Four-wheel differential drive

primary and safest base

3

Ultrasonic + tracking sensors

for obstacle and edge awareness

5

6

USB serial link

4

Two-wheel + caster

4

through laptop if connected

7

separate 3S motor pack

Shared ground + protected wiring

BUILD PRIORITY

SAFE BASE

4-wheel drive · camera · display

CORE AI

Pose · hand · phone · laptop audio

EXPLORE

2-wheel base · audio · arm if feasible

07

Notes: Video preprocessing converts OpenCV frames from BGR to RGB, samples the frame rate, crops relevant regions, normalizes model inputs, and preserves timestamps. Audio is converted to fixed-rate mono windows, with RMS or relative sound-pressure level used for volume detection and an optional Log-Mel spectrogram used for classification. Face samples are detected, aligned, normalized, and filtered for darkness, blur, or excessive angle. Baseline and Basic Model development require calibration and testing data, while Advanced Model training requires labeled landmark or multimodal sequences.

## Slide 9

AUTONOMOUS BEHAVIOUR

DETECT

Video frames and

current robot state

CONFIRM

Temporal voting and

confidence threshold

Action priority with

distance and safety rules

ACT

Move, turn, servo, display

and sound through the laptop

COOLDOWN

Resume monitoring after

user response or timeout

SELECT

Show timer and stretch cue

Approach or turn toward the user

Return after acknowledgement

SITTING TOO LONG

Display a refocus prompt

Move or react when usage persists

Gesture acknowledges the reminder

PHONE DISTRACTION

Start, pause or reset the focus timer

Robot confirms with display and motion

Manual stop remains available

GESTURE INPUT

Low speed, distance limits, obstacle sensing and cooldowns remain active during every behaviour.

AUTONOMOUS DOES NOT MEAN UNCONTROLLED

08

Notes: Frame-level predictions must be stabilized before they trigger a reminder. Moving averages, exponential smoothing, or majority voting reduce jitter, while duration and entry-exit thresholds prevent brief or oscillating states from generating events. Phone confidence, head direction, and system events can be fused, and gestures require confirmation across multiple frames. Low-confidence decisions return unknown, reminders use cooldown periods, and all thresholds remain adjustable through user testing.

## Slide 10

10-DAY DELIVERY PLAN

18–27 JULY 2026

BUILD CORE FIRST; ADD EXTENSIONS ONLY AFTER THE END-TO-END DEMO WORKS

DELIVERY STRATEGY

VERTICAL SLICE

Every stage ends with a runnable demo

Must: drive + video + laptop audio

Should: posture / phone / gesture DL

Could: identity, 2-wheel base, arm

DAYS 1–2 · FOUNDATION

Drive, sensors, power and serial link

Produce a remotely testable moving base

Camera + pose / face / hand / phone

Validate frame rate and event quality

DAYS 3–4 · PERCEPTION

THEN POLISH

DAYS 5–6 · RESPONSE

Unified events → Arduino actions

Add timer, display, servo and movement

DAYS 9–10 · TEST + DEMO

and complete end-to-end scenarios

DAYS 7–8 · INTEGRATE

MVP FIRST

Tune thresholds

Run scenario tests, polish behaviour, prepare slides and backup video

Failsafe: each AI event can be simulated so hardware and interaction remain demonstrable

09

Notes: The Advanced Model is optional and is introduced only when the Basic Model cannot classify continuous behaviour reliably. Candidate extensions include temporal posture classification, dynamic gesture recognition, phone-detector fine-tuning, multimodal off-task behaviour classification, noise-type recognition, and personalization. The recommended extension is a small TCN or GRU trained on normalized hand-landmark sequences with dimensions T by twenty-one by three. This input is compact, reduces background interference, and avoids training directly on raw video.

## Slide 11

APPENDIX: OPTIONAL EXTENSIONS

ONLY AFTER CORE DEMO

USE ONLY WHEN CONTINUOUS BEHAVIOUR IS NOT STABLE IN THE PRE-TRAINED PIPELINE

RECOMMENDED LEARNED EXTENSION

DYNAMIC GESTURE

normalized hand-landmark sequence

Wave, swipe, and circle classes

Low-dimensional training input

Lower background and privacy risk

CONTINUOUS POSTURE

Small MLP, 1D-TCN, or GRU

Normalized body-landmark sequence

Fine-tune a lightweight detector

Small targets and partial occlusion

PHONE DETECTOR

TCN OR GRU

OFF-TASK BEHAVIOUR

TCN/GRU or multimodal MLP

Phone, head direction, idle time, events

PERSONALIZED CALIBRATION

Requires an external microphone

AUDIO CLASSIFICATION

T × 21 × 3

Pre-trained YAMNet via laptop

User-specific distance, posture and usage baselines

Goal: reduce variation between users without making personalization a core dependency

10

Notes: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

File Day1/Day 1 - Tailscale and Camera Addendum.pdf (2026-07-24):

Setting Up your own VPN
Connecting two devices over the internet can be tricky due to firewalls, NAT, and other network configurations. A VPN (Virtual Private Network) allows you to create a secure connection between your devices over the internet, making it easier to access your Raspberry Pi from anywhere in the world ( or even on the Moon ). In this section, you will set up a VPN using TailScale, (https://typst.app) a popular and user-friendly VPN service based on the WireGuard protocol.
Creating a Tailscale Account and Installing Tailscale on your Laptop
1. On your laptop, go to Tailscale (https://tailscale.com/) and sign up for a free account using your email.
2. Once you have created your account, log in to the Tailscale web interface.
3. Download and install the Tailscale client for your laptop’s operating system (Windows, macOS, or Linux) from the Tailscale website (Download Page). (https://tailscale.com/download) Follow the installation instructions provided on the website.
Once you have installed Tailscale on your laptop, open the Tailscale application and log in using the account you just created. Your laptop should now be connected to the Tailscale VPN. You can verify this on your tailscale dashboard, (https://login.tailscale.com/admin/machines) where you should see your laptop listed as a connected device.

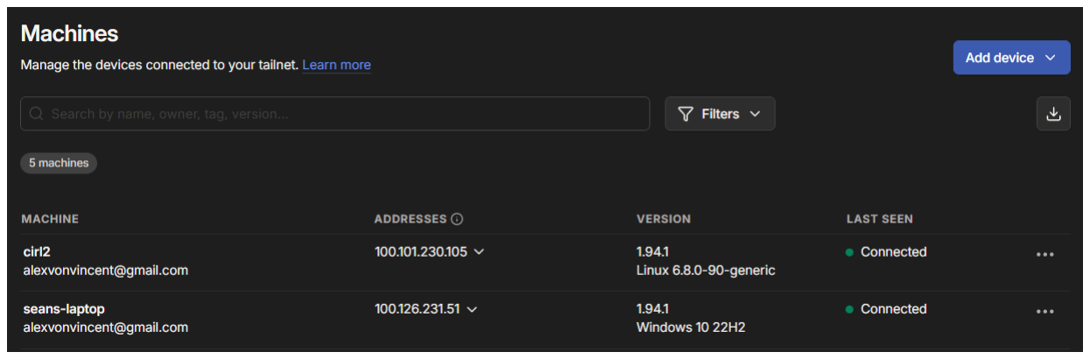
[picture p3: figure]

Figure 1: Tailscale Dashboard showing connected devices. In this case, I have quite a few devices connected! My laptop’s name is seans-laptop.

Note: Getting your team connected to the Pi
Get your groupmates to also create Tailscale accounts and install the Tailscale client on their laptops. You will have to invite (https://tailscale.com/docs/features/sharing/how-to/invite-team-members) them to your Tailscale network later. This will allow everyone in your subgroup to access the Raspberry Pi remotely.
You can have a maximum of 3 unique users per tailnet (i.e., tailscale network) on the free account. If you want more users, we suggest that your entire group create and share a Tailscale account for simplicity.

Setting up Tailscale on your Raspberry Pi
Now that you have Tailscale set up on your laptop, it’s time to install and configure Tailscale on your Raspberry Pi. Make sure your Raspberry Pi is powered on and connected to the internet. Open a terminal on your Raspberry Pi (you can use the terminal application in the Raspberry Pi OS desktop environment). Run the following commands:

# Lines starting with '#' are comments, do not type them in

# These commands will update the package list and install any updates if available. # Just in case the provided OS image is outdated

# or the previous update did not complete successfully.

sudo apt-get update
sudo apt-get upgrade

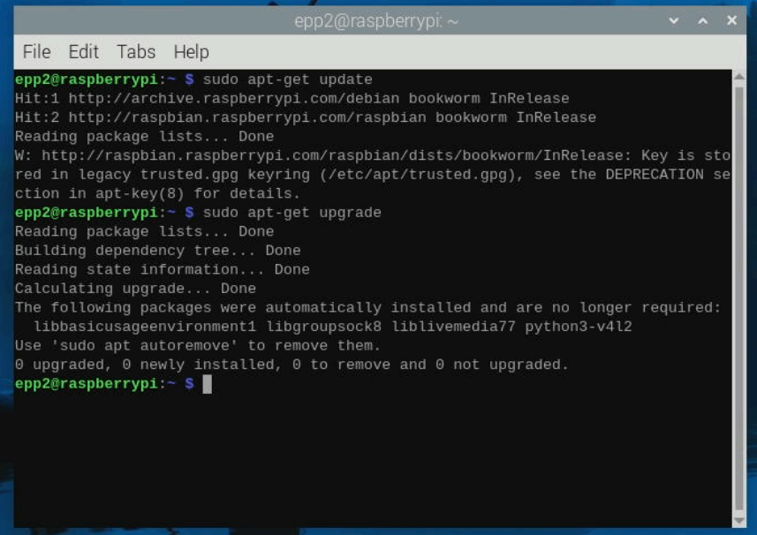
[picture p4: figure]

Next, install Tailscale by running the following command:

# We will download the official installation script from Tailscale

# (using the program curl) and execute it to install Tailscale on the Pi.

curl -fsSL https://tailscale.com/install.sh | sh

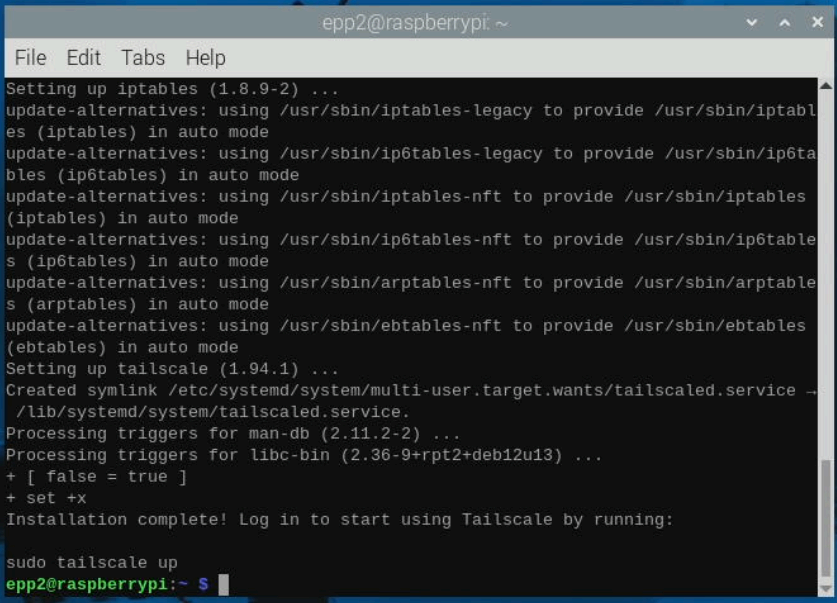
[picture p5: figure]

Once installed, you can attempt to start Tailscale and authenticate your Pi to your Tailscale account by running:

# This command will start the Tailscale service and provide you with a link to

# authenticate your Raspberry Pi to your Tailscale account.

# It should also set up to automatically start the Tailscale service on boot. sudo tailscale up

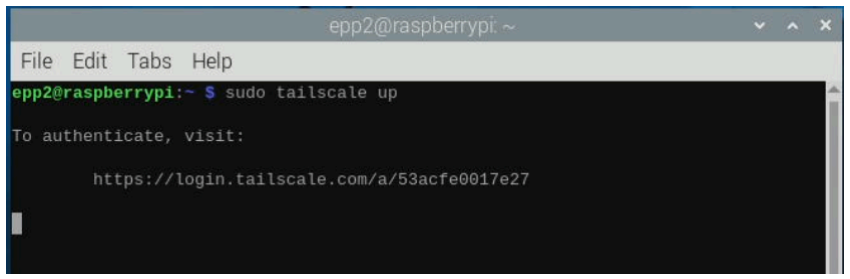
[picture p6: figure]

Proceed to the link provided in the terminal output (Do not use mine! it will not work!) to authenticate your Raspberry Pi to your Tailscale account. You may need to log in to your Tailscale account if you are not already logged in.

Connect the Pi to your Tailscale network by clicking “Connect” on the web page.

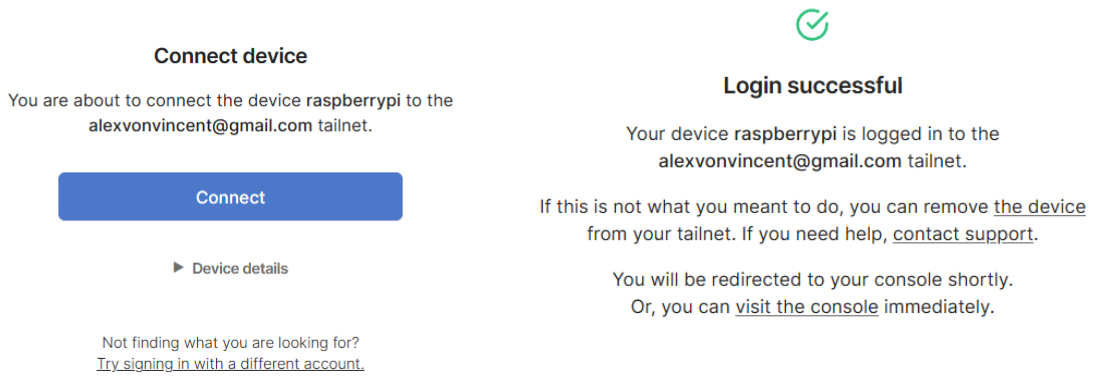
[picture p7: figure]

If you followed the steps correctly, your Raspberry Pi should now be connected to your Tailscale VPN. You can verify this by checking the Tailscale dashboard on your laptop.

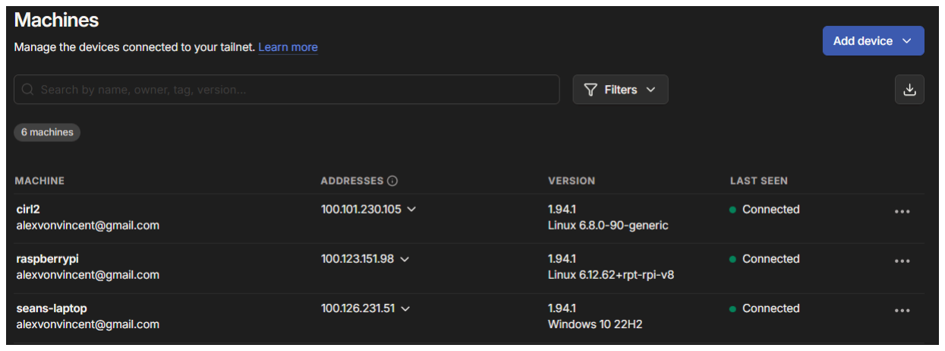
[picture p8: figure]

Figure 2: My Raspberry Pi is named raspberrypi. Finally, to prepare for remote access, you need to enable the SSH server on your Raspberry Pi. Run the following command on your Raspberry Pi and navigate to “Interfacing Options” -> “SSH” -> “Enable”:

# This command allows access to many configuration options for the Raspberry Pi. # We will use it to enable SSH.

sudo raspi-config

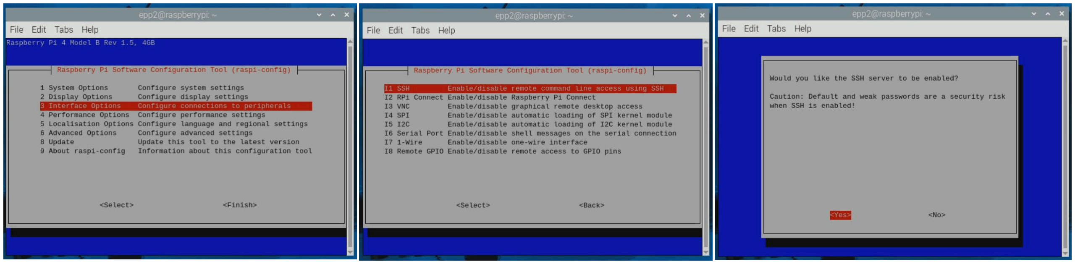
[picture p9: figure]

Testing the Tailscale Connection Via SSH (From your Laptop!)

Note
From this point, you theoretically don’t need to keep the monitor, keyboard, and mouse connected to the Raspberry Pi anymore. For the true headless engineering experience, you can unplug them for the remainder of the lab! (Plugging them back in is also fine if you need to troubleshoot anything.)

Congratulations! You have successfully set up Tailscale on your Raspberry Pi and enabled the SSH server. Now, let’s test the connection by SSHing into your Raspberry Pi from your laptop using the Tailscale IP address.
First obtain your Raspberry Pi’s Tailscale IP address. You can find this on the Tailscale dashboard on your laptop.

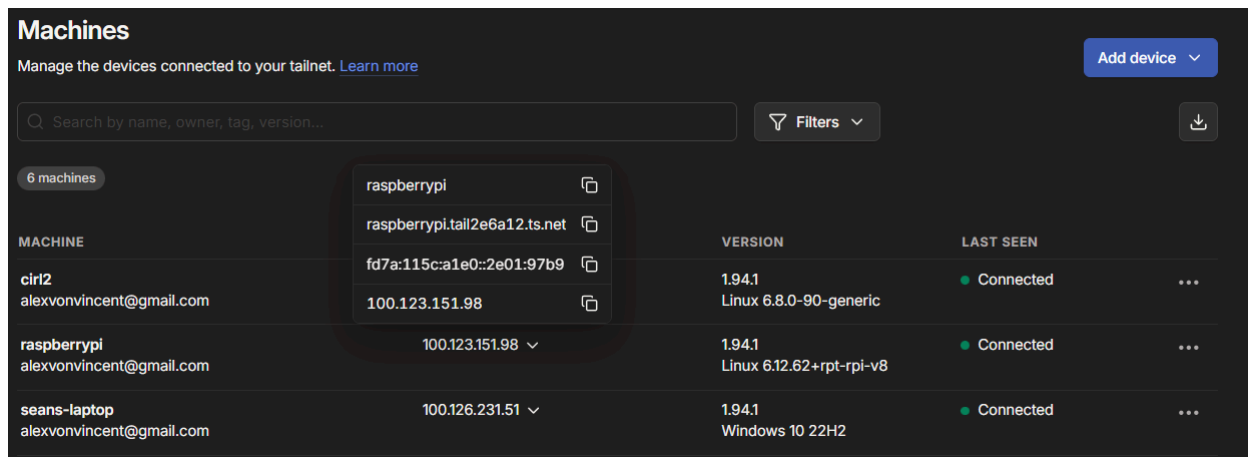
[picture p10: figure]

Figure 3: Finding the Tailscale IP address of the Raspberry Pi on the Tailscale dashboard. In this case, it is 100.123.151.98
Take note of the Tailscale IP address of your Raspberry Pi (it should be in the format 100.x.x.x). This address is unique to your Raspberry Pi within your Tailscale network. You will need this IP address to SSH into your Raspberry Pi from your laptop.

Open a terminal on your laptop and run the following command, replacing <TAILSCALE_IP> with your Raspberry Pi’s Tailscale IP address and <USERNAME> with the username you set during the Raspberry Pi OS setup (default is “pi”):

# If you have taken CS1010 / CS1010E, you should be familiar with SSH.

# Just that now, we are using our very own VPN to connect to the Pi remotely. ssh <USERNAME>@<TAILSCALE_IP>

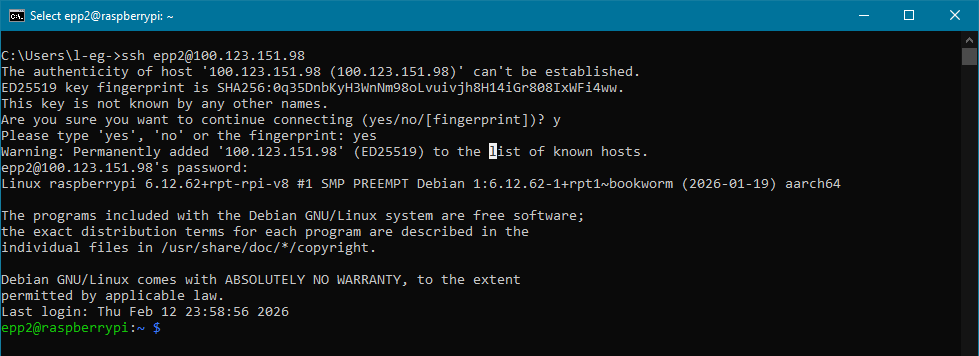
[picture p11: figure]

Figure 4: The username I set for my Pi is “epp2” and my tailscale IP is 100.123.151.98, so I ssh into epp2@100.123.151.98. I hope you remember your password! If everything is set up correctly, you should now be logged into your Raspberry Pi via SSH! You can now run commands on your Raspberry Pi remotely from your laptop. You can now shut down your Pi to prepare for the next step.

# This command will shut down the Pi immediately.

sudo shutdown now

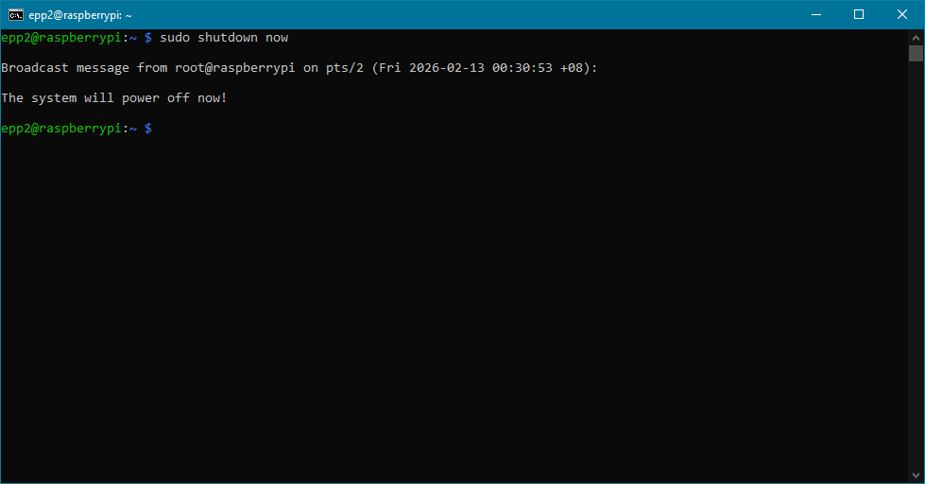
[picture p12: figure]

Figure 5: Make sure to shut down the Pi properly before unplugging power!

Setting up the Pi Camera
In this section, you will set up the Raspberry Pi Camera Module and take a photograph using it, then transfer the photograph to your laptop.

Note
Security alert! After these steps, you’ve added a privacy sensitive sensor to your Raspberry Pi. Please cover your camera or unplug your Pi when not in use.

Connecting the Pi Camera Module
The Raspberry Pi Camera Module is a small camera that connects to the Raspberry Pi via a dedicated camera interface (CSI). It allows you to capture high-quality images and videos. We provide the Pi Camera 3, which is compatible with the Raspberry Pi 4. Make sure that the Raspberry Pi is powered off before connecting the camera module to avoid any damage.

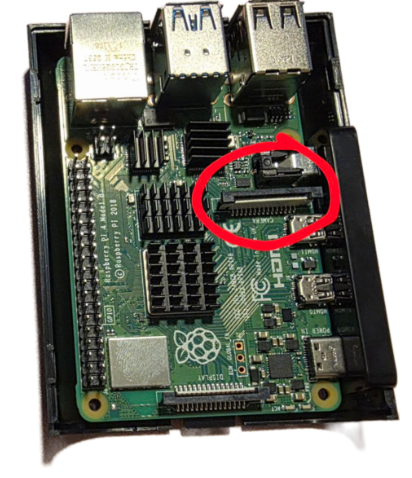
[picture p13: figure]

Figure 6: Camera CSI port is the one closer to the ‘center’ of the board.

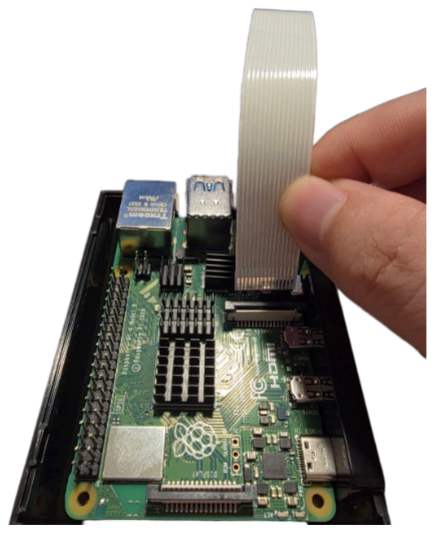
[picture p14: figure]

Figure 7: Metal contacts face towards the HDMI ports.

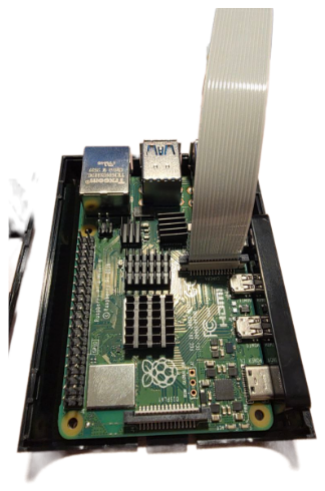
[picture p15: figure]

Figure 8: Fully seated camera cable with the clip securely holding it in place.
Follow these steps to connect the Pi Camera Module to your Raspberry Pi:
1. Locate the Camera Serial Interface (CSI) port on the Raspberry Pi. It is a small, flat connector located near the HDMI ports.
2. Gently lift the plastic clip on the CSI port to open it.
3. Insert the camera cable into the CSI port with the metal contacts facing towards the HDMI ports. Make sure the cable is fully seated in the port.
4. Push the plastic clip back down to secure the camera cable in place.

Testing the Pi Camera
Now that the Pi Camera Module is connected, it’s time to test it out by taking a photograph. First, power on your Raspberry Pi by connecting it to a power source. Wait for it to boot up completely (about a minute).
Once the Pi is booted up, SSH into your Raspberry Pi from your laptop using the Tailscale IP address as described in the previous section.
The Raspberry Pi OS provides some pre-installed programs (https://www.raspberrypi.com/documentation/computers/camera_software.html#rpicam-apps) for you to interact with the camera. To test the camera connection, run the following command on your Raspberry Pi:

# This command will test if the camera is connected properly.

rpicam-jpeg --list-cameras

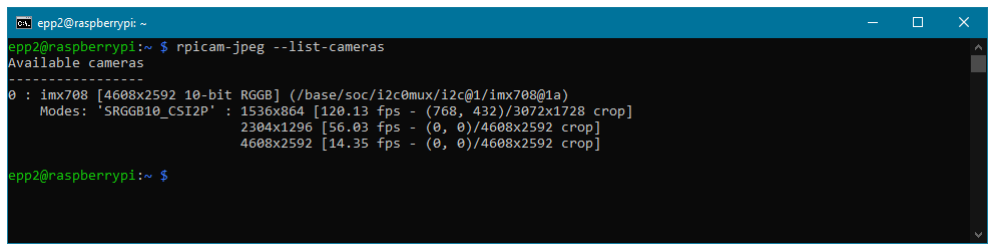
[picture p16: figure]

Figure 9: Output of rpicam-jpeg --list-cameras. If you see “0: imx708” listed, the camera is detected successfully!
Now that the camera is detected, you can take a photograph using the following command:

# This command will take a photograph and save it as 'image.jpg' in the current directory

# The rpicam-jpeg program has many camera options that you can explore later. You can check them using the '-h' flag

rpicam-jpeg --output test.jpg

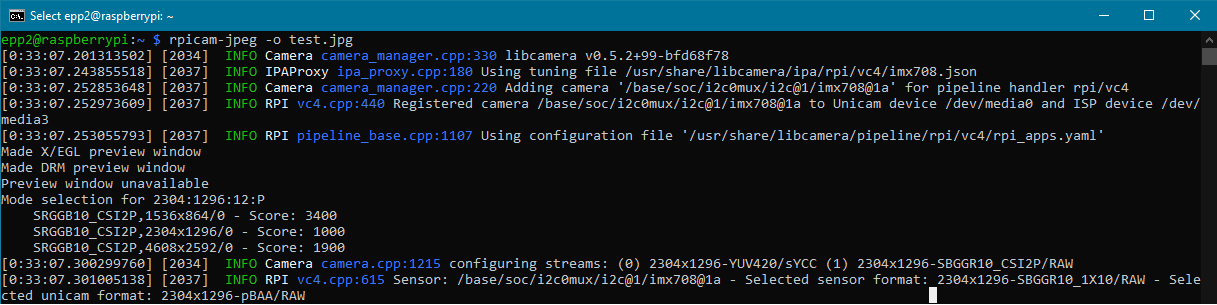
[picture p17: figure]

Check that the photograph has been taken successfully by listing the files in the current directory.

# You should be familiar with this command from CS1010. It lists the files

# in the current directory. You should see 'test.jpg' in the output.

ls

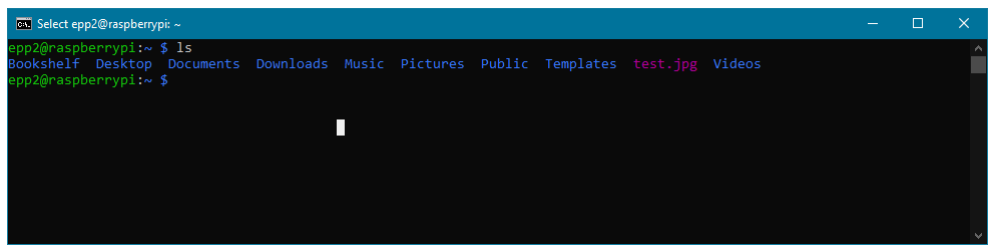
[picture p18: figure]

Figure 10: You can see ‘test.jpg’ in the output of ls, which means the photograph was taken and saved successfully!
To really check that the photograph was taken successfully, you can transfer the photograph to your laptop using SCP (Secure Copy Protocol) over SSH.
Open another terminal on your laptop and run the following command, replacing <USERNAME> with your Raspberry Pi username, <TAILSCALE_IP> with your Raspberry Pi’s Tailscale IP address, and <DESTINATION_PATH> with the path on your laptop where you want to save the photograph:

# This command will copy the 'test.jpg' file from your Raspberry Pi to your laptop. Make sure to specify the correct path on your laptop where you want to save the file. scp <USERNAME>@<TAILSCALE_IP>:~/test.jpg <DESTINATION_PATH>

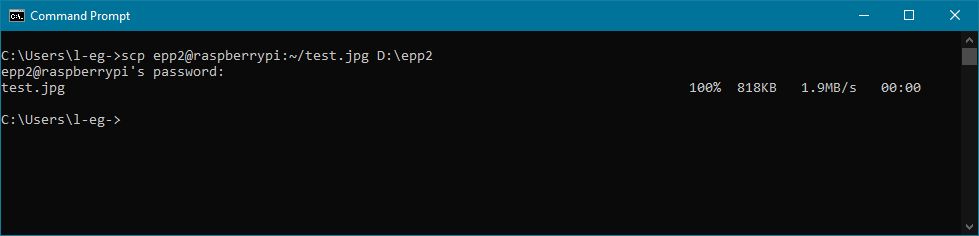
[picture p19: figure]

Now if we open the photograph on your laptop, you should see the image captured by the Pi Camera Module!

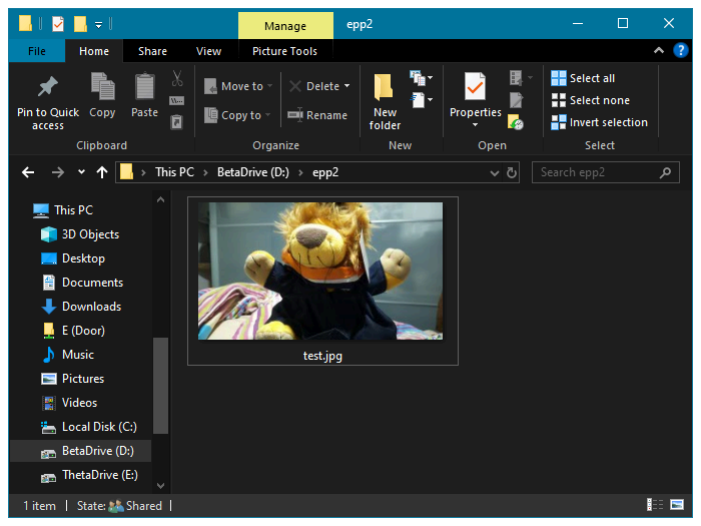
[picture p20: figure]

Congratulations! You have successfully set up the Raspberry Pi Camera Module and taken a photograph using it.

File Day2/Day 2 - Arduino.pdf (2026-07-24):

1

## SWS3009 – Part B

## Robotics / TeleOperation

Section 3: Arduino Mega

## Outline

◼ Arduino Basics
❑ Introduction
❑ Programming
❑ External components demonstration

2

## ARDUINO BASICS

## Arduino Family says Hi!

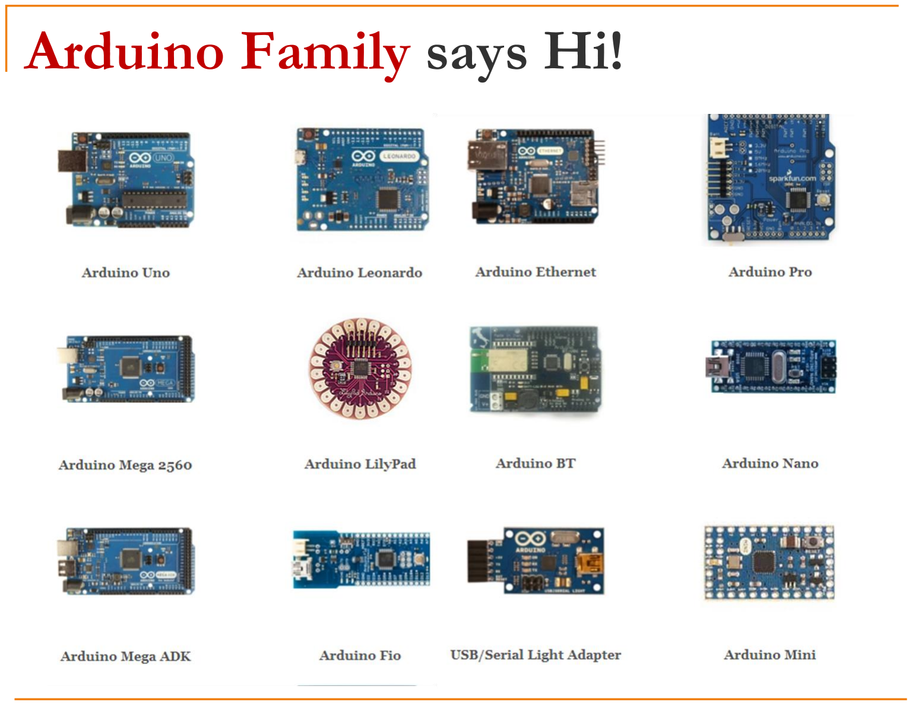
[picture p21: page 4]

Our Arduino….

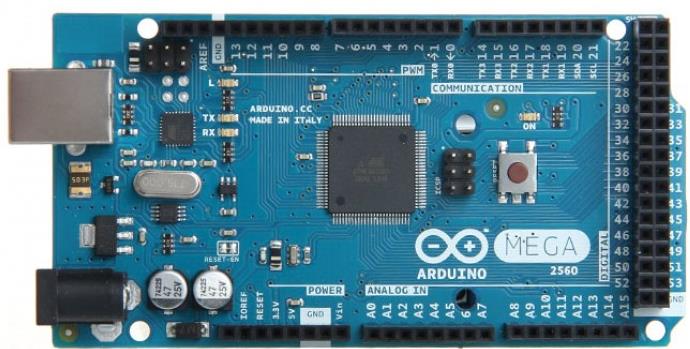
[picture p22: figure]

◼ Arduino Mega 2560 (Revision 3)
❑ Note that the reset button may be located differently (e.g. corner of the board)

## Arduino Mega 2560 - Layout

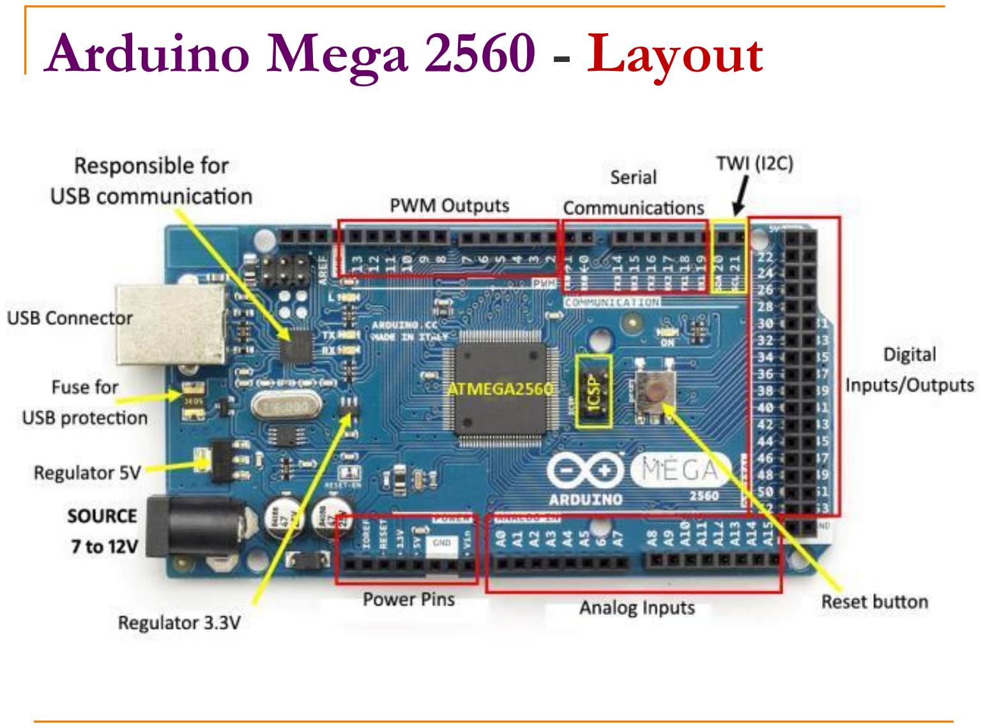
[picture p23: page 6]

## Arduino Mega: Basic Facts

◼ Microcontroller Board
❑ Based on ATmega2560
◼ USB connection
❑ Alternative Powering Option: Power Jack ◼ Input / Output Capabilities
❑ 54 digital input/output pins

◼ 14 can be used for PWM output (more later)
❑ 16 analog inputs

◼ Digitized to 10 bits (i.e. 1024 levels)
❑ 4 UART (Serial Ports)
❑ 16MHz Crystal Oscillator (Clock Signal)

## Breadboards… how do they work?

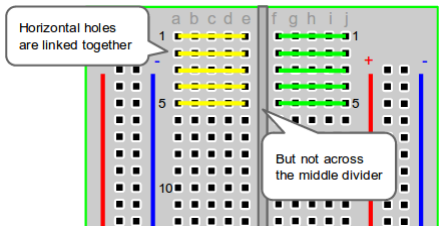
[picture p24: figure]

Image source: https://computers.tutsplus.com/tutorials/how-to-use-a-breadboard-and-build-a-led-circuit--mac-54746

## Breadboards… how do they work?

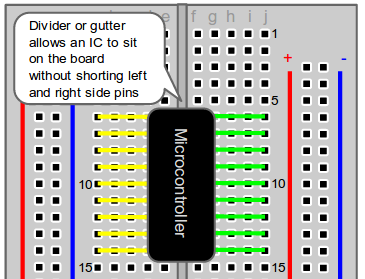
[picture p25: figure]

Image source: https://computers.tutsplus.com/tutorials/how-to-use-a-breadboard-and-build-a-led-circuit--mac-54746

## Breadboards… how do they work?

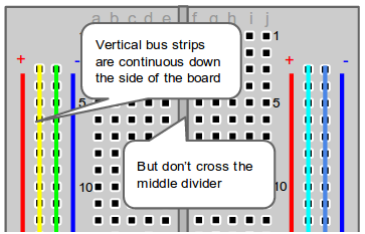
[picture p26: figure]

Image source: https://computers.tutsplus.com/tutorials/how-to-use-a-breadboard-and-build-a-led-circuit--mac-54746

## LED Task


Use a 220 Ohm resistor

## Introducing Arduino IDE


◼ Arguably the main
reason for Arduino's
popularity

◼ Minimalistic but
beginner friendly
and reasonably
powerful

## Programming on Arduino

◼ Programming Language:
❑ Subset of C/C++
❑ Limited set of C/C++ libraries
❑ Additional set of Arduino specific calls

Online Reference at; https://www.arduino.cc/en/Reference/HomePage; ◼ Program structure:; ❑ Minimally need the setup() and loop() functions; ❑ Additional functions can be declared; Global Variables; void setup(); void loop()

## Blink: An example program

◼ pinMode( pin, mode )

❑ | pin = pin number
❑ | mode = { INPUT, OUTPUT }

◼ digitalWrite( pin, value )
❑ pin = pin number
❑ value = 0 / 1 (use LOW /
| HIGH constant!)

◼ delay( ms )
❑ ms = millisecond

void setup() {

pinMode(13, OUTPUT);

}

void loop() {

digitalWrite(13, HIGH);
delay(1000);

digitalWrite(13, LOW);
delay(100);

}

## Question: Let's Blink Differently

◼ How do we change the blinking patterns as following:

◼ A: Blink twice in a second

◼ B: Blink short-short-long

◼ C: Blink randomly
❑ (Hint: Look for the correct library call in Arduino)

## Communication

◼ Since we cannot easily debug the code on the Arduino directly
❑ we will use basic serial communication as a "debugging" mechanism

## Serial Communication: Idea


◼ Serial
Communication is
a very old idea

◼ Still commonly
supported:
❑ Only need 2 wires
for two way
communication!

### Serial Communication: Arduino Mega

◼ Arduino Mega support 4 sets of serial communication (two ways each):
❑ Serial 0: Through the USB connection or Pin 0 (Receive RX) + Pin 1 (Transmit TX)
❑ Serial 1: Pin 19 (RX) + Pin 18 (TX),
❑ Serial 2: Pin 17 (RX) + Pin 16 (TX)
❑ Serial 3: Pin 15 (RX) + Pin 14 (TX)

◼ Be careful: Check the operating voltage of the device you want to communicate with: ❑ Arduino Mega operates at 5 volt

## Serial Communication: Code


1. Note the use of "Serial"
2. Click ( or press Ctrl-Shift-M") to open the serial
monitor
3. Let's see it in action!

## Serial Communication: Code 2

void setup() {

Serial.begin( 9600 );
Serial.println( "Hello World!" );

}

void loop() {

if (Serial.available()) {
int inByte = Serial.read(); Serial.print("Read: ");
Serial.print(inByte);
Serial.print(" 0x");
Serial.println(inByte, HEX); }

}

## Serial Communication: Code 2


Try sending a message here

Can you figure out what did we type?

## EXTERNAL COMPONENTS

## Interfacing with Components

◼ Arduino can interface with many electronic components

◼ Common steps:
1. Connect the electronic components to the correct pin(s)
◼ Usually wiring diagram is provided
2. Write code to interact with the component:
◼ Sometimes, libraries are provided together with the components

## Ultrasonic Sensor - Principle


## Ultrasonic Sonic - Implementation


◼ Given Echo Time Pulse (i.e. time difference between Chirp and Echo), how do we get the distance, D?

1

2

3

## Ultrasonic Sensor: Connection

any 5v supply pin

## Ultrasonic Sensor: Operation


digitalWrite(TRIGGER, LOW); delayMicroseconds(2);
digitalWrite(TRIGGER, HIGH); delayMicroseconds(10);
digitalWrite(TRIGGER, LOW); duration = pulseIn(ECHO, HIGH); cm = duration / 58 ;

## Ultrasonic Sensor: Adding Libraries

◼ In this case, the ultrasonic sensor manufacturer provided sample library to use the sensor in a painless way

◼ In Arduino, select Library Manager > Search for “NewPing by Tim Eckel” and click Install.

◼ [For exploration] You can take a look in the library code to see the details, e.g. how to trigger a pulse, how to measure echo time pulse, etc

## Ultrasonic Sensor: Code Example


◼ Understand the code:
❑ Especially on how to define the pins used correctly
1. Change the
baud rate
2. Move the ultrasonic
sensor around and observe
the data

## DC MOTOR

## DC Motor: Speed and Direction


1. Turning speed is control by PWM
2. Turning direction is handled by H-Bridge

## Controlling the Speed of Motor

◼ Intuitively, we can control the speed of motor by varying the voltage supply

◼ So, if 5v == maximum speed, supplying 2v should give us a slower speed…

◼ The idea is correct, but there is a problem…

## Pulse Width Modulation (PWM)

◼ Sometimes we need to
have analog output:
❑ e.g. varying amount of
power to the motor will
modify the speed
◼ PWM enables us to
simulate analog output
by switching on/off
rapidly on an digital
output channel
◼ Pin 2 to 13, 44 to 46
supports PWM


## Exercise: PWM for LED

◼ Let's try to use PWM to control the brightness of the LED
❑ Conveniently, Pin 13 supports PWM!
❑ See code Blink_PWM.ino

◼ [Additional Challenge] Write a program to control the brightness of LED using Serial Communication

## Controlling the Direction of Motor

◼ H-Bridge involve multiple electronic components (e.g. transistor, resistor etc)
◼ Imagine the messiness if we need to control 2-4 wheels
◼ Motor Driver / Motor Shield is a commonly seen integrated component that provide H-bridge functionality

◼ We use the Dual L293D Motor Driver Arduino Shield:
❑ Can control up to 4 motors!

## Controlling the Direction of Motor


## Dual L293D Motor Shield


Motor 1

Motor 2

Motor 4

Motor 3

External Battries to provide higher voltage + current

## Motor Shield: Library

◼ Basic functionality is provided by the "Adafruit Basic Motor Shield”. Install using Arduino library manager.


## INTERRUPT HANDLING

Excuse me! Excuse me!

39

## Motivation

◼ Imagine your Arduino is running some code: ❑ However, if the external emergency stop button is pressed, you are supposed to stop processing immediately

◼ Main question is:
❑ How do we handle external event?

◼ Possible solution:
❑ Keep checking whether the event occurs, BUT this is not very efficient (time is wasted)

40

## Motivation

void setup() {
Serial.begin(9600);
}

void loop() {
Serial.print("Working hard..."); delay(1000); //Do some work Serial.println("done.");
}

41

## Interrupt: What is it?

◼ Most processors provide alternative mechanisms to handle these events: ❑ e.g. interrupt

◼ When the external event happens:
1. A signal is generated
2. The processor automatically execute code to handle the event:
◼ The code is commonly known as interrupt handler
3. After the event is handled, the processor resume the work it was performing prior to the event

42

## Interrupt: Arduino Mega

◼ Interrupt handler in Arduino Mega is known as Interrupt Service Routine (ISR)

◼ There are 6 digital pins, each given a specific interrupt number:

Digital Pin Number | Interrupt Number
2 0
3 1
21 2
20 3
19 4
18 5

Note: the Arduino
function
digitalPinToInterrupt()
helps to convert pin
number to interrupt
number

43

## Interrupt In Action: Code (1/2)

const byte ledPin = 13;
const byte interruptPin = 2; volatile byte state = HIGH;

void setup() {
pinMode(ledPin, OUTPUT);
pinMode(interruptPin, INPUT_PULLUP);

attachInterrupt(
digitalPinToInterrupt(interruptPin), blink, CHANGE );

digitalWrite(ledPin, state); Serial.begin(9600);
}

See "ISR-Simple.ino"

44

## Interrupt In Action: Code (2/2)

void loop() {
Serial.print("Working hard..."); delay(1000);
Serial.print("done. State = "); Serial.println(state);
}

void blink() {
state = !state;
digitalWrite(ledPin, state); }

45

## Interrupt In Action: Connection

◼ We are going to use a simple trick to "simulate" a button press / change in input for pin 2

◼ Steps:
1. Upload the sketch and open the Serial Monitor.

◼ Observe the output
2. Connect a male-to-male wire into pin 2. Leave the other end unconnected.
3. To simulate a change for pin 2, insert the other end to a ground pin and then quickly remove it.

46

## Important Functions

◼ pinMode( XXX, INPUT_PULLUP)
❑ inverts the behavior of the pin, where HIGH means the input device is off, and LOW means the input device is on
◼ attachInterrupt( IRNum, ISR, mode)
❑ IRNumber: The interrupt number (NOT the pin number). Use digitalPinToInterrupt( pin ) to convert easily
❑ ISR: The Interrupt Service Routine. The ISR should be a void XXXX() function.
❑ mode: Triggering mode, see next slide

47

## Four Interrupt Trigger Modes


◼ Triggering Mode is based on the feature of the signal:

LOW
Triggers when the pin is low

RISING
Triggers when the pin goes from low to high

FALLING
Triggers when the pin goes from high to low

CHANGE
Triggers when the
pin changes value

48

## Explanation

◼ This code demonstrates the scenario where: ❑ the loop() is doing some work
❑ need to react to change in pin 2 (e.g. if it is connected to a button)

◼ How does it work?
❑ Whenever the pin 2 experienced a change, the ISR "blink()" is executed automatically
❑ blink() inverts the state of the LED (high➔low, low➔high)
❑ the loop() resumes automatically after blink() returns

49

## Writing ISR: Rules of Thumb

1. Make ISR as short as possible
❑ Common trick: Set a flag / update value in the ISR and let the main loop to do the time consuming part
2. Do not use delay() in ISR
3. Do not use Serial read/write in ISR
4. If a variable is shared between ISR and
| other code, declare it as volatile:
❑ | Ensure correct compiler handling
◼ | Caution: When an ISR is executing, all other interrupts have to wait!
❑ | May miss important event!

50

## Your Tasks for the Afternoon

◼ | Get your Arduino up and going
◼ | Run through all the examples (time to play).
❑ | Blink, Serial, Ultrasonic, DC Motor, Interrupts
◼ | Can you use an interrupt to turn on an LED based on the
distance measured by the ultrasonic sensor?

◼ Try out the analog thumbstick! Can you get it working? (requires some googling)

◼ Pick a sensor from the sensor box and get it working!

51

## END

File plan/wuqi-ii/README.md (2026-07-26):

# wuqi-ii：J/L 人脸居中转向交接说明

## 目标

这份目录只保存 `wuqi-ii` 负责的左转、右转人脸居中功能相关文件快照和交接说明，不包含完整项目，也不作为树莓派的直接运行目录。

- `J`：向左开始搜索人脸，发现人脸后逐步修正到画面中心并停车。
- `L`：向右开始搜索人脸，发现人脸后逐步修正到画面中心并停车。
- DroidCam 和人脸检测运行在 Windows 电脑。
- 转向状态机和电机 PWM 控制运行在树莓派。
- 源代码快照来自提交 `faaa928f81bb277867c901d43ba0d18448d95f6d`。

## 文件清单

所有快照都位于 `left_right_face_turn/`，并保留正式项目中的相对路径。

| 文件 | 作用 |
| --- | --- |
| `pi_service/robot_web/templates/index.html` | 显示 J/L 左右转按钮和快捷键说明，并通过查询参数刷新前端脚本缓存。 |
| `pi_service/robot_web/static/app.js` | 监听 Edge 中的 `J`、`L` 键以及页面按钮，向树莓派发送开始转向请求。 |
| `pi_service/robot_web/app.py` | 提供 `/api/autonomous/face-turn` 接口，接收 `START`、`OBSERVE`、`CANCEL`。 |
| `pi_service/robot_web/end_line_turn_adaptor.py` | 在树莓派上执行“短脉冲转动 → 停车等待画面稳定 → 检查人脸偏差”的闭环状态机。 |
| `pi_service/experiments/droidcam_face_turn_validation/droidcam_face_turn.py` | 在 Windows 读取 DroidCam、检测人脸并持续上报人脸中心位置。 |
| `pi_service/experiments/droidcam_face_turn_validation/README.md` | DroidCam 工具的运行说明。 |
| `pi_service/experiments/droidcam_face_turn_validation/test_droidcam_face_turn.py` | DroidCam 人脸转向工具的单元测试。 |
| `pi_service/experiments/droidcam_face_turn_validation/__init__.py` | 实验工具的 Python 包标记。 |

## 数据流

1. Windows 先运行 `droidcam_face_turn.py`，默认读取 `DroidCam Video` 对应的摄像头编号 `1`。
2. 用户在 Edge 网页中按 `J` 或 `L`。
3. `app.js` 向树莓派发送：

   ```json
   {"action": "START", "direction": "LEFT"}
   ```

   或：

   ```json
   {"action": "START", "direction": "RIGHT"}
   ```

4. Windows 的 DroidCam 进程以默认 8 FPS 检测人脸，并向同一接口发送 `OBSERVE`，包含：

   - `found`：是否检测到人脸；
   - `frame_width`：DroidCam 画面宽度；
   - `center_x`：人脸框中心的横坐标。

5. 树莓派将人脸中心换算为归一化偏差：

   ```text
   offset = (center_x - frame_width / 2) / (frame_width / 2)
   ```

6. 人脸不在中心时，树莓派按偏差方向执行一次短脉冲转动；脉冲结束后立即停车，等待画面稳定，再处理新的人脸帧。
7. 人脸连续满足居中条件后，状态机关闭转向权限并停车。

## 当前调参

参数定义在 `end_line_turn_adaptor.py`：

| 参数 | 当前值 | 含义 |
| --- | ---: | --- |
| `FACE_TURN_PWM` | `90` | 原地转向短脉冲 PWM。 |
| `FACE_PULSE_SECONDS` | `0.10 s` | 单次转动持续时间。 |
| `FACE_SETTLE_SECONDS` | `0.32 s` | 每次转动后的画面稳定等待时间。 |
| `FACE_CENTER_TOLERANCE` | `0.10` | 允许的人脸水平归一化偏差。 |
| `FACE_CENTER_CONFIRM_FRAMES` | `4` | 连续居中确认帧数。 |
| `FACE_MAX_PULSES` | `40` | 最大转动脉冲次数。 |
| `FACE_TURN_TIMEOUT_SECONDS` | `25 s` | 单次任务总超时时间。 |
| `FACE_OBSERVATION_TIMEOUT_SECONDS` | `1 s` | DroidCam 观测中断判定时间。 |

## 安全行为

- 收不到第一帧 DroidCam 观测时保持停车。
- DroidCam 观测超过 1 秒未更新时，以 `FACE_STREAM_LOST` 结束并停车。
- 超过 25 秒仍未居中时，以 `FACE_TURN_TIMEOUT` 结束并停车。
- 达到 40 次脉冲仍未居中时，以 `FACE_PULSE_LIMIT` 结束并停车。
- 达到连续 4 帧居中后，以 `FACE_CENTERED` 结束并停车。
- `CANCEL`、空格键或 DroidCam 工具退出时会请求取消并停车。

## 运行顺序

树莓派使用正式项目路径启动网页控制服务：

```bash
cd /home/g11/Desktop/pi_service
bash run_end_line_turn_console.sh
```

Windows 在正式仓库根目录启动 DroidCam 观测进程：

```powershell
python pi_service/experiments/droidcam_face_turn_validation/droidcam_face_turn.py
```

随后在 Edge 打开：

```text
http://100.80.46.54:5000
```

首次更新后使用 `Ctrl+F5` 强制刷新，再用 `J`、`L` 测试。

只验证人脸检测而不发送电机控制请求时：

```powershell
python pi_service/experiments/droidcam_face_turn_validation/droidcam_face_turn.py --preview-only
```

## 维护说明

`plan/wuqi-ii/left_right_face_turn/` 是交接快照。后续修复应先修改正式的 `pi_service/` 文件并完成测试，再更新本目录中的对应快照，避免正式代码和交接文件出现差异。

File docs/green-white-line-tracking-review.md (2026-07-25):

# 绿底白线 I 型巡线方案评审与收敛记录

## 1. 范围

本文只讨论当前仓库中完整可读、可独立运行的绿底白线 I 型巡线模式：

```bash
./pi_service/run_green_white_scanline_i_console.sh
```

对应运行模式为 `scanline_i_green_white`。本文不讨论：

- 黑线 / Otsu 巡线；
- 缺少 `third_party/DeskMate-Advance` 源码的 generic 路线；
- 更换相机采集链路；
- 深度学习；
- 本轮不必要的复杂状态估计或硬件升级。

当前目标是在现有相机、现有 OpenCV 和现有电机接口上，优先解决：

1. 车辆经常冲出白线；
2. 转弯角度不精确；
3. 车辆冲出或转错后很难恢复；
4. 方案过度依赖车辆始终处于正确初始位置和正确朝向。

## 2. 已确认不处理的部分

### 2.1 相机取帧

相机取帧链路已经完成实测，本轮不修改、不作为问题来源继续展开。

涉及代码：

- `pi_service/robot_web/camera.py`
- `pi_service/robot_web/scanline_i_route.py`

## 3. 当前绿底白线控制链

```text
run_green_white_scanline_i_console.sh
    -> app.py 选择 scanline_i_green_white
    -> GreenWhiteScanlineIShapeRouteTracker
    -> GreenWhiteHybridScanlineAnalyzer
    -> HSV 绿底 / 白线 / 红色标记分割
    -> 近端连通域选择
    -> 三行扫描线 + 横线 / 骨架证据
    -> IShapeTurnaroundPlanner
    -> 直行差速 PWM 或右向原地掉头
    -> RobotController.set_direct_drive()
    -> Arduino M1/M2
```

主要代码：

- 启动：`pi_service/run_green_white_scanline_i_console.sh`
- 模式装配：`pi_service/robot_web/app.py`
- 绿底白线和红色识别：
  `pi_service/experiments/i_shape_green_white_turnaround_validation/green_white_scanline_i_logic.py`
- 扫描线、横线和状态机：
  `pi_service/experiments/i_shape_scanline_turnaround_validation/scanline_i_logic.py`
- 实车 PWM：
  `pi_service/robot_web/scanline_i_route.py`
- 直行 PWM 公式：
  `pi_service/experiments/straight_line_stop_validation/straight_motor_control.py`
- 串口电机输出：`pi_service/robot_web/controller.py`

## 4. 三行扫描线与工字端点

### 4.1 当前实现

直线跟踪采样画面底部三行：

```python
track_rows = (0.92, 0.86, 0.80)
```

横向端点使用单独的宽线检测逻辑。宽度超过
`narrow_width_ratio` 的横线不会直接作为直线目标。因此，工字端点横线的设计意图是
“作为端点证据，不参与左右纠偏”。

视觉层允许至少两条窄线扫描结果就形成有效路线：

```python
minimum_track_rows = 2
```

但电机层存在另一条更严格的规则：

```python
if offset is None or valid_bands < 3 or abs(offset) <= deadband:
    return straight_pwm, straight_pwm
```

因此：

- 三行全部有效：允许按偏差差速纠偏；
- 只有两行有效：视觉仍可认为路线有效，但电机强制双轮同速直行；
- 没有中心偏差：同样强制双轮同速直行。

### 4.2 对问题的判断

`valid_bands < 3` 不是门槛太低，而是纠偏门槛太严格。

工字横线进入近场后，可能遮盖、合并或截断纵向白线，使三个窄线采样退化为两行或
更少。此时当前控制不会根据剩余有效偏差纠正方向，反而输出直行 PWM。这会造成：

- 接近端点时继续冲直线；
- 车体已经偏斜时不再修正；
- 端点触发位置严重依赖速度、摩擦和车辆初始姿态。

### 4.3 收敛建议

本轮不引入复杂曲线拟合，先做保守规则：

1. 三行有效：正常 P 纠偏；
2. 两行有效：允许纠偏，但降低基础 PWM，并限制最大修正；
3. 一行有效：视为退化状态，低速或短时保持，不允许正常巡航；
4. 零行有效：进入明确的丢线处理，禁止把 `offset=None` 当作直行。

两行有效时应使用两行中心的中位数，并增加连续帧确认，避免一帧横线碎片引发强转向。

## 5. 骨架与前视点

### 5.1 当前实现

当前代码已经计算骨架、路口、路径和前视点；骨架默认每两帧更新一次。现有直行 PWM
并未使用前视点，只使用底部三行的 `line_center_x`。

### 5.2 本轮决定

骨架不是当前最小修复的必要条件。本轮不把骨架前视点接入核心电机控制，原因是：

- 调试成本较高；
- 骨架毛刺、分支和缓存仍需要额外处理；
- 当前最严重问题可以通过扫描线、红色触发窗口和状态机修复；
- 需要优先得到可解释、可实车标定的行为。

骨架继续保留用于：

- 横线 / 路口辅助检测；
- 调试预览；
- 日志；
- 后续确有需要时再评估是否用于前视控制。

## 6. 普通丢线问题

### 6.1 当前严重缺口

`FOLLOW_STRAIGHT` 没有普通丢线分支。

当前实际链路是：

```text
白线丢失
    -> planner 仍处于 FOLLOW_STRAIGHT
    -> FOLLOW_STRAIGHT 仍属于前进状态
    -> line_center_x 为 None
    -> drive_pwm_for_offset() 把 None 映射为双轮同速
    -> 车辆继续以 straight_pwm 前进
```

这是冲出线路后继续冲、并且无法自动恢复的直接原因，属于必须优先修复的安全问题。

### 6.2 丢线帧数

“丢线 1～2 帧立即决定转弯”不稳定，不应仅凭短暂白线丢失触发掉头。普通丢线与工字
端点掉头必须使用不同证据：

- 普通路线丢线：降速、停止或有限恢复；
- 工字端点掉头：必须由红色标记窗口和白色端点共同授权。

### 6.3 收敛建议

普通 `FOLLOW_STRAIGHT` 中：

1. 一帧丢线：不触发掉头，立即降低或保持很低的前进输出；
2. 连续少量丢线：停车，不允许继续正常直行；
3. 没有红色窗口授权时，任何丢线都不能进入 180° 掉头；
4. 重新看到白线后，需要连续确认再恢复正常巡航。

具体确认帧数和低速 PWM 必须通过录像与实车标定，作为网页可调参数保存。

## 7. 双红色标记定义转弯窗口

### 7.1 目标

不使用“丢线 1～2 帧”直接判断掉头，而在工字端点附近贴两段独立红色标记，用它们的
可见性组合定义一个可标定的转弯区间。

预期原则：

```text
红色标记组合尚未进入标定窗口：只巡线，不允许掉头
进入标定窗口：允许白色横线 / 纵线结束触发停车和掉头
离开标定窗口或组合不符合预期：不允许掉头，执行降速或停车
```

用户提出的核心触发关系是：两段红色中，一段应已经不在视野内，另一段仍在视野内。
这一组合用于表示车辆进入了一个可调整的物理位置范围。

### 7.2 与当前红色检测的区别

当前代码寻找的是“同一高度上、分列白线左右两侧的两个红色碎片”，并将它们合并成
一个红色横带。

用户提出的“两段红色”可能是沿行驶方向分开的两个独立位置标记。二者不是同一个
概念，实施前必须明确贴法：

- 方案 A：两段红色沿行驶方向前后排列，用先后可见性定义窗口；
- 方案 B：每个位置仍由白线左右两块红色组成，共设置前后两个红色横带。

若采用方案 A/B 的前后窗口，检测器需要分别维护 `near_marker` 和 `far_marker`，不能
继续把所有同高度红色碎片只合并成一个 marker。

### 7.3 独立红色 ROI

红色识别应使用独立 ROI，不与白线扫描行完全共用。建议参数化：

- 红色 ROI 的顶部和底部；
- 近红标记允许的 y 范围；
- 远红标记允许的 y 范围；
- 最小红色面积和跨度；
- 连续确认帧数；
- 标记消失确认帧数。

只有红色组合进入窗口后，状态机才设置 `turn_authorized=True`。

红色 ROI 的目的：

- 排除画面远处红色物体；
- 排除教室环境中的红色椅子等干扰；
- 防止红色标记刚进入远端视野就过早授权掉头；
- 将触发位置变成可现场调节的像素范围。

## 8. 收敛后的端点状态机

建议本轮使用以下简单状态，不引入复杂全局定位：

```text
FOLLOW
    正常三行巡线

DEGRADED
    只有一到两行，或短暂丢线；降速，不允许掉头

TURN_WINDOW_ARMED
    双红色可见性组合进入标定窗口；继续低速接近

BRAKE
    红色窗口已授权，白色横线 / 纵向线结束确认；停车

PULSE_PIVOT
    小步进右转

CHECK_ALIGNMENT
    每次步进后停车并重新识别

REACQUIRE
    白线重新进入合适位置，低速对准

FOLLOW
    连续确认后恢复

SAFE_STOP
    超时、红色组合矛盾或一直找不到白线
```

普通丢线绝不能直接跳到 `PULSE_PIVOT`；只有
`TURN_WINDOW_ARMED + 白色端点确认` 才能开始掉头。

## 9. 小步进转向、停车识别

### 9.1 对方案的理解

用户提出的方案是：

```text
短时间转动
    -> 停车
    -> 获取稳定图像并识别
    -> 未对准则继续下一次短转
    -> 已对准则结束掉头
```

这比当前“PWM 200 连续盲转至少 2.5 秒”更适合现有系统，且不需要额外硬件。

### 9.2 建议控制变量

建议将以下参数做成网页可调：

- `pivot_pulse_pwm`
- `pivot_pulse_seconds`
- `pivot_settle_seconds`
- `pivot_max_pulses`
- `reacquire_confirm_frames`
- `reacquire_center_tolerance`
- `reacquire_spread_tolerance`

### 9.3 每次停车后的识别条件

本轮可先只使用现有扫描线，不强制使用骨架：

1. 至少两行或三行窄白线有效；
2. 白线中心位于可调中心范围；
3. 三行中心离散程度小，说明白线大致沿车身纵向；
4. 连续多帧满足；
5. 当前画面不再是宽横线占主导。

满足这些条件后，先低速直行对准，再恢复正常巡航。

### 9.4 注意事项

停车后需要等待短暂稳定时间再识别，否则车身惯性、相机振动和运动模糊会使第一帧
不可靠。转向脉冲也不能过短到电机尚未克服静摩擦，必须通过实车标定最小有效脉冲。

## 10. 本轮暂不采用的复杂方案

为保持实现可解释、适配现有硬件，本轮暂不采用：

- Kalman Filter；
- MPC；
- 完整 Pure Pursuit；
- 鸟瞰二次曲线控制；
- 骨架前视点直接控制电机；
- 新增传感器；
- 重构相机采集链；
- 自动全局定位。

这些方案不是永久否定，而是在基础安全状态机、双红色窗口和步进掉头验证前不优先。

## 11. 必须补充的测试

### 11.1 直行与丢线

- `FOLLOW` 中 `line_center_x=None` 不得输出正常直行 PWM；
- 两行有效时进入降速纠偏，不得无条件双轮 120；
- 一帧丢线不触发掉头；
- 未进入红色窗口时，持续丢线最终必须停车；
- 白线重新出现后需要连续确认再恢复。

### 11.2 红色转弯窗口

- 两段红色均在错误 ROI 时不授权；
- 只有远端红色时不授权；
- 只有符合标定组合时才授权；
- 短暂漏检一帧不改变授权状态；
- 授权必须在离开窗口或完成掉头后清除；
- 红色授权本身不能直接驱动电机掉头，仍需白色端点确认。

### 11.3 脉冲掉头

- 每次只执行一个有上限的转向脉冲；
- 脉冲后必须进入停车识别；
- 未对准时继续下一脉冲；
- 对准连续确认后结束转向；
- 超过最大脉冲数必须 `SAFE_STOP`；
- 看到斜线或偏在画面边缘时不得直接恢复高速巡线。

## 12. 当前优先级

1. 先建立第 15 节的版本化运行日志，使每次失败可追溯；
2. 修复普通 `FOLLOW_STRAIGHT` 丢线仍直行；
3. 拆开 `offset=None`、两行有效和真正居中三种情况；
4. 确定两段红色的实际贴法和可见性组合；
5. 实现独立红色 ROI 与 `TURN_WINDOW_ARMED`；
6. 用脉冲转向 + 停车识别替代连续 2.5 秒盲转；
7. 增加对应单元测试和离线帧序列测试；
8. 实车低速标定红色窗口、转向脉冲和停车稳定时间。

## 13. 待讨论项

在进入实现前，需要最终确定：

1. 两段红色是沿行驶方向前后排列，还是每个位置各由左右两块红色组成；
2. 转弯窗口期望的确切组合是“近标记可见、远标记不可见”，还是相反；
3. 两段红色之间的实际距离；
4. 相机中红色标记从远端进入到离开底部的大致 y 范围；
5. 步进掉头允许的总耗时和场地空间；
6. 掉头过程中始终向右转，还是需要根据场地端点决定方向。

## 14. 两个外部循迹仓库的可借鉴项

参考仓库：

- `CRM-UAM/VisionRace`
- `DexterTaha/WRO-2024-FUTURE-ENGINEERS`

本节结论来自源码核对，不直接采用外部仓库 README 中未经代码实现支持的描述。

### 14.1 CRM-UAM/VisionRace

#### 源码中的实际方法

`line_follow.py` 使用一条水平扫描线：

1. 对灰度图做阈值处理；
2. 对扫描行执行 `np.diff()`；
3. 用一对正负跳变边沿确定线的左右边界；
4. 取两个边沿中点作为横向目标；
5. 用中点偏差直接形成左右轮差速；
6. 当前扫描行找不到边沿时，向上移动扫描行并逐步降低速度；
7. 多次找不到线后退出并停车。

#### 不可直接复制

该仓库最后提交时间较早，`line_follow.py` 本身存在明显问题：

- `tresh` / `thresh` 拼写不一致；
- `img` 未定义；
- 缩进混乱；
- 丢线计数在重获后没有重置；
- 清理函数在调用点之后才定义；
- 只取最先出现的两个边沿，存在多目标误配风险。

因此不能把它当作可直接运行或已经验证稳定的实现。

#### 对当前项目真正有价值的部分

1. **缺失时降速而不是继续正常直行。**

   这直接支持当前评审结论：`offset=None` 不能映射为
   `straight_pwm, straight_pwm`。

2. **在固定底部扫描失败后，向更远处补充扫描。**

   当前项目不需要照搬循环移动单条扫描线，可以在 `DEGRADED` 状态增加若干
   recovery rows。它们只能用于重新寻找纵向窄线，不能直接触发正常高速巡航。

3. **给丢线恢复设置明确次数上限。**

   连续失败计数必须在可靠重获后重置；达到上限后必须 `SAFE_STOP`。

4. **边沿成对验证。**

   当前项目的 `_row_run()` 已经把连续白色区间分组并取得左右边界，本质上比
   VisionRace 的“取前两个跳变点”更完整。因此无需改成 `np.diff()`，只需继续验证
   区间宽度和跨行一致性。

#### 不建议借鉴

- 单条扫描线作为唯一巡线依据；
- 直接选取最前两个边沿；
- 从底部一直循环扫描整个画面；
- 该仓库的直接差速公式和代码结构。

### 14.2 DexterTaha/WRO-2024-FUTURE-ENGINEERS

#### 源码中的实际方法

`src/imageProcessing/utils.py` 的颜色目标检测使用：

1. HSV 独立颜色 mask；
2. 中值滤波；
3. 膨胀和腐蚀；
4. `findContours()` 获得颜色连通域；
5. 用相对画面面积过滤小目标；
6. 用 `boundingRect()` 得到目标中心、宽度和高度；
7. 根据已知目标尺寸和像素高度粗略估算距离；
8. 根据目标横向位置区分目标在左侧还是右侧。

#### 不可直接复制

该仓库使用阿克曼转向、墙线和额外传感器，不是当前差速 I 型白线场景。源码还存在：

- 视觉函数返回值与主循环解包数量不一致；
- 距离参数和像素到厘米换算是固定近似；
- `atan` 转向角公式针对其彩色障碍和阿克曼机构；
- README 提到的 crash handling、Kalman 等没有形成可复用的完整闭环。

因此不能直接移植其转角计算、主循环或恢复逻辑。

#### 对当前项目真正有价值的部分

1. **红色检测输出候选列表，不要只输出一个 best marker。**

   当前项目为了双红色前后窗口，需要为每个红色候选保留：

   ```text
   center_x
   center_y
   width
   height
   area
   span
   ```

   然后按 y 位置排序和跨帧关联，而不是在检测器内过早合并成一个红色结果。

2. **使用相对 ROI 面积过滤。**

   红色最小面积应相对红色 ROI 计算，使分辨率改变时阈值仍有一致含义。

3. **使用目标框高度 / 面积作为接近程度的辅助量。**

   对尺寸固定的红色胶带，越靠近相机，通常像素高度和面积越大。当前项目不应把它
   换算成声称精确的厘米距离，但可以作为：

   - 远标记；
   - 进入窗口；
   - 接近底部；
   - 已经过车；

   的粗粒度证据。

4. **颜色目标与路线检测分层。**

   红色只负责授权转弯窗口；白色横线继续负责端点确认；电机状态机最终决定动作。
   这与当前收敛方案一致。

#### 不建议借鉴

- 直接使用仓库中的 `atan` 结果控制当前差速掉头；
- 把边界框像素尺寸直接当作准确物理距离；
- Hough 墙线导航；
- 阿克曼转向命令；
- README 中没有被当前源码落实的 crash recovery 描述。

### 14.3 合并后适合当前项目的最小改进

两个参考仓库没有提供比当前项目更成熟的完整循迹闭环，但支持以下低复杂度改进：

1. 保留现有三行扫描和 `_row_run()`；
2. 三行退化时增加少量、更高位置的 recovery rows；
3. recovery rows 只允许低速恢复，不允许直接高速巡航或触发掉头；
4. 丢线时逐级降速，并设置连续失败上限；
5. 红色检测返回多个经过面积过滤的候选框；
6. 使用红色候选的 y、框高度和面积做远近分区；
7. 用跨帧历史确认“A 已经过、B 正在指定 ROI”；
8. 红色窗口授权后仍需白色端点确认；
9. 掉头继续采用本项目计划的“脉冲转动 -> 停车 -> 扫描线确认”，不照搬外部仓库。

### 14.4 对当前优先级的影响

外部参考没有改变第 12 节的总体优先级，只补充了两点：

- `DEGRADED` 状态可用额外扫描行扩大有限恢复范围；
- 双红色检测应从“单一最佳红带”改为“候选列表 + 面积/位置/尺寸 + 时序关联”。

其余关键问题仍必须由当前项目自身解决，特别是：

- `FOLLOW_STRAIGHT` 丢线仍直行；
- 两行有效时强制双轮同速；
- 连续 2.5 秒盲转；
- 转弯结束缺少停车对准确认。

## 15. 运行日志与调试规范

### 15.1 目标

每次电机输出必须能够反向追溯到：

1. 同一帧的 OpenCV 视觉证据；
2. 状态机状态、计数器和跳转原因；
3. 当时生效的参数版本；
4. PWM 计算分支和最终下发值；
5. 控制器报告的串口及电机输出状态。

日志采用 UTF-8 JSON Lines。每行是一个完整 JSON 对象，禁止依靠解析自由文本来恢复状态。

### 15.2 公共字段

所有记录必须包含：

```text
schema_version
event
run_id
drive_session_id
time_utc
monotonic_seconds
frame_id
config_revision
```

- `time_utc` 用于人工定位；
- 状态机计时和帧间耗时只使用 `monotonic_seconds`；
- `run_id` 标识进程内的一次视觉运行；
- 每次按 M 开始自动行驶生成新的 `drive_session_id`；
- 网页参数每成功应用一次，`config_revision` 加一。

单位必须进入字段名：

- 像素：`*_px`；
- 秒：`*_seconds`；
- 比例：`*_ratio`；
- PWM：`*_pwm`；
- 帧计数：`*_frames`。

空值语义固定为：

- `null`：本帧无法计算；
- `false`：执行了检测且结果为否；
- `0`：测得或计数确实为零；
- 字段缺失：当前 schema 没有定义该字段。

### 15.3 事件类型

当前必须支持：

- `session_start`：记录模式、画面尺寸、软件版本和完整参数快照；
- `session_end`：记录正常停止或异常结束原因；
- `drive_enabled` / `drive_disabled`：记录 M 门控变化；
- `frame_observation`：逐帧视觉、planner、控制和控制器状态；
- `state_transition`：状态变化时额外记录稳定原因码和证据摘要；
- `tuning_changed`：记录参数旧值、新值、应用帧和新 revision；
- `error`：记录异常类型、消息、traceback、状态和最后帧号。

暂停预览时可降采样为约每秒一条；自动行驶时每个处理帧都必须记录。状态跳转、调参和错误不得采样丢弃。

### 15.4 当前逐帧字段

`frame_observation` 分成四组：

1. `vision`
   - `confidence`、`valid_line`、`line_lost`；
   - `line_center_x_px`、`valid_bands`；
   - 每个有效扫描行的 `y_px`、`row_ratio`、`center_x_px`、`width_px`；
   - endpoint、junction、red band 和 lookahead。
2. `planner`
   - `state`；
   - 稳定枚举 `reason_code` 与说明性 `reason_detail`；
   - endpoint、丢线、重获、junction 帧计数和掉头耗时；
   - 红色底部授权、红色消失帧数及快速丢线授权状态。
3. `control`
   - 控制分支；
   - 归一化偏差、死区、增益；
   - 原始和限幅后的修正 PWM；
   - 基础 PWM、左右轮指令及限幅原因。
4. `controller`
   - 串口是否打开、Arduino 是否在线；
   - 最近接收数据年龄；
   - Arduino 报告的电机输出和错误。

当前 `ScanlineEvidence` 只保留被接受的扫描行。因此日志可以可靠记录“该行有效及其中心/宽度”，但不能推测被拒绝候选的原因。后续修改视觉数据模型时，应为每个配置扫描行增加：

```text
detected
accepted
candidate bounds
reject_reason
```

建议的拒绝原因枚举：

```text
NO_COMPONENT
WIDTH_TOO_NARROW
WIDTH_TOO_WIDE
TRANSVERSE_BAR_DOMINANT
DISCONNECTED_FROM_NEAR_ROUTE
OUTSIDE_ROUTE_CORRIDOR
LOW_COLOR_CONFIDENCE
```

### 15.5 稳定原因码

状态跳转使用固定枚举，例如：

```text
WHITE_BAR_CONFIRMED
EARLY_BAR_PREDICTED
RED_EXIT_CONFIRMED
LINE_LOST_CONFIRMED
REACQUIRE_CONFIRMED
BAR_TIMEOUT
PIVOT_STARTED
PIVOT_LIMIT_REACHED
USER_ENABLED
USER_PAUSED
UNHANDLED_EXCEPTION
```

动态坐标和解释放入 `reason_detail`，禁止把坐标拼接进原因码。

### 15.6 双红色窗口的后续日志契约

实现双红色标记时，检测器必须输出候选列表，而不是只输出合并后的最佳红带。每个候选至少记录：

```text
x_px, y_px, width_px, height_px, area_px
roi_class
accepted
reject_reason
```

状态机另行记录：

```text
near_marker_visible
far_marker_visible
near_confirm_frames
far_missing_frames
turn_window_authorized
authorization_reason
```

未实现双红色候选前，不得在运行日志中伪造这些字段。

### 15.7 脉冲掉头的后续日志契约

每次脉冲必须产生一个 `pivot_cycle` 事件，至少包括：

```text
pulse_index
phase
pulse_pwm
requested_pulse_seconds
actual_command_seconds
settle_seconds
valid_bands
center_offset
center_spread_px
alignment_confirm_frames
alignment_accepted
reject_reason
```

未实现脉冲掉头前，当前连续掉头统一记录为 `control.mode=PIVOT_CONTINUOUS`，不得误称为脉冲控制。

### 15.8 图像证据与人工标记

下一阶段应增加 2～3 秒原始帧环形缓冲，只在以下事件保存前后帧：

- `FOLLOW -> DEGRADED`；
- 普通丢线；
- 红色窗口授权；
- 刹车和每次掉头脉冲；
- 重获成功或失败；
- `SAFE_STOP`；
- 异常；
- 操作者点击“标记问题”。

同时保存原图和标注图，并用 `run_id + frame_id + event` 命名。该功能只依赖已有相机/OpenCV，不要求新增硬件。

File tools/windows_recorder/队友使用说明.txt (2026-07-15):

Robitics 本地 JPG 记录器（默认 5 FPS）
========================================

用途
----
从树莓派的视频地址读取 MJPEG 视频流，将图片直接保存到本机电脑。
图片不会保存到树莓派。

使用前
------
1. Windows 电脑需安装 Python 3（安装时勾选 Add Python to PATH）。
2. 确保浏览器可以打开：http://树莓派IP:5000/video_feed

使用方法
--------
1. 双击“启动本地JPG记录器.bat”。
2. 在“树莓派视频流地址”填写实际地址，例如：
   http://100.80.46.54:5000/video_feed
3. 点击醒目的“选择保存位置…”按钮，选择要保存 JPG 的文件夹。
4. 点击“开始保存（5 FPS）”。
5. 点击“停止保存”结束。

说明
----
- 默认每秒保存 5 张 JPG。
- 网络断开时自动每 3 秒重试。
- 剩余磁盘空间低于 5 GB 时自动停止，避免写满磁盘。

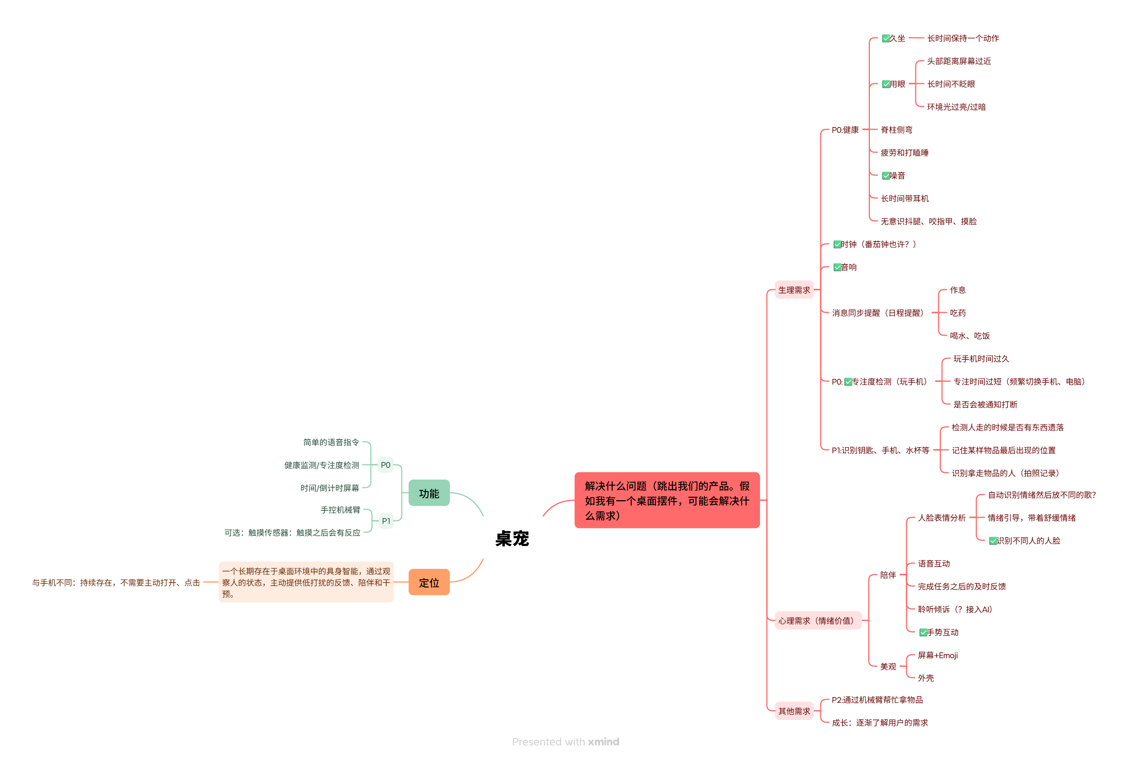
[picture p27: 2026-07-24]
assets/project_images/桌宠_2.png

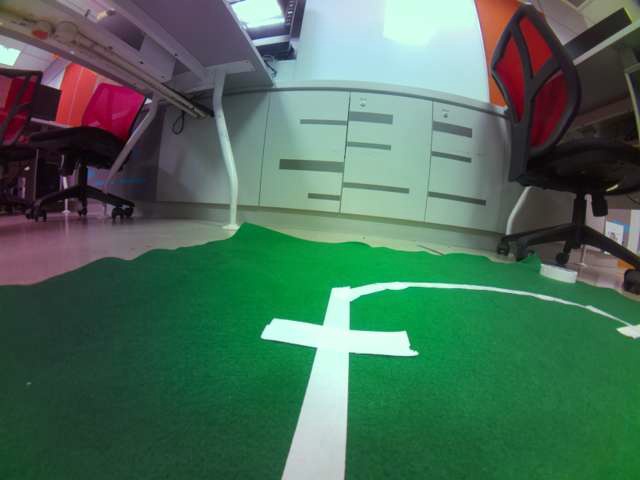
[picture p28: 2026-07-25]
artifacts/green_white_live_preview_moved.jpg

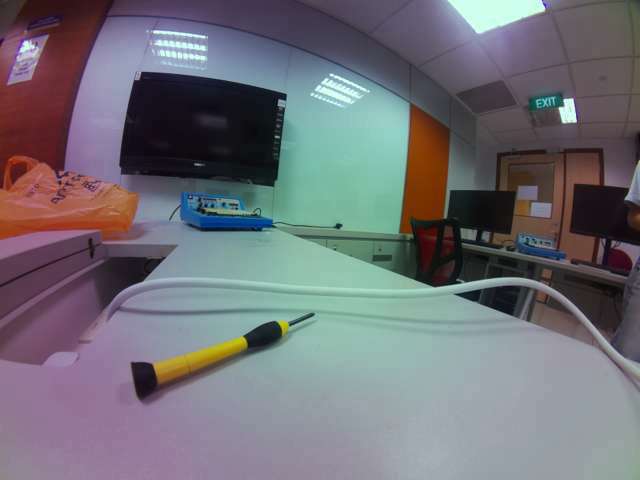
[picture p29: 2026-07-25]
artifacts/green_white_live_preview.jpg

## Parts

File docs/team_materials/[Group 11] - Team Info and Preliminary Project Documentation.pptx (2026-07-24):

## Team 11 – Loss Hunters

Seek, Detect, Recover.

[SWS3009 - Let's Start]

## Team Members


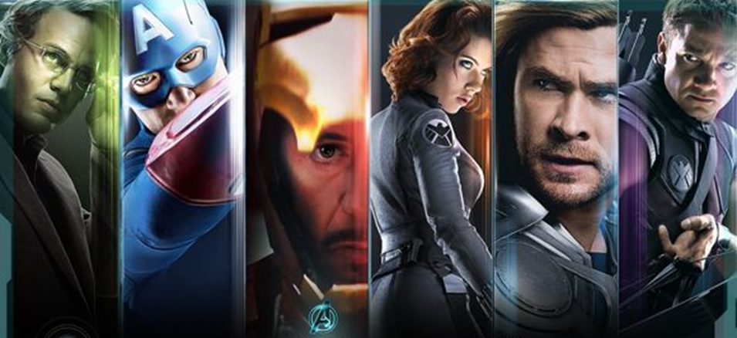
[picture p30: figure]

## Our Aims

- In this program, we hope to understand how robotics, deep learning, and tele-operation can work together in a real-world system. We aim to build a robot that can perceive its environment, recognize target objects, and support remote human control. Through this project, we want to improve our skills in hardware integration, computer vision, system design, and teamwork.

## Baseline Model Specification

- Visual Perception Detect small objects and determine whether the user is watching. Solution: use object detection and face/head-pose recognition.
- Precise Interaction Move or hide objects safely without falling from the desk. Solution: use edge sensors, low-speed control, and a simple scoop or magnet.
- System Integration Ensure reliable communication between Raspberry Pi and Arduino. Solution: use serial communication, feedback signals, and manual override.

## Our COOL Idea - Overview

- Our advanced model is an AI-powered lost item hunting robot. The robot uses a camera and deep learning object detection to identify target items such as keys, bottles, or bags. It can move around a room, search for objects, and report the detected location to the remote user. The user can also take over control through tele-operation when the robot faces complex situations.

## Key Problems

- Visual Perception Detect small objects and determine whether the user is watching. Solution: use object detection and face/head-pose recognition.
- Precise Interaction Move or hide objects safely without falling from the desk. Solution: use edge sensors, low-speed control, and a simple scoop or magnet.
- System Integration Ensure reliable communication between Raspberry Pi and Arduino. Solution: use serial communication, feedback signals, and manual override.

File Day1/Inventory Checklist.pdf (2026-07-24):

Storage Box Inventory Checklist | Page 1

# STORAGE BOX INVENTORY CHECKLIST

# Photo Inventory and Packing Verification

Inventory Categories | 23
Photo Records | 23
Document Date | July 2, 2026

Each photographed item is listed with its recorded quantity.

Use the final checklist page to verify all items during packing or unpacking.

# PHOTO INVENTORY

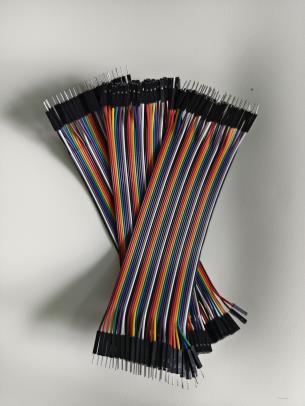
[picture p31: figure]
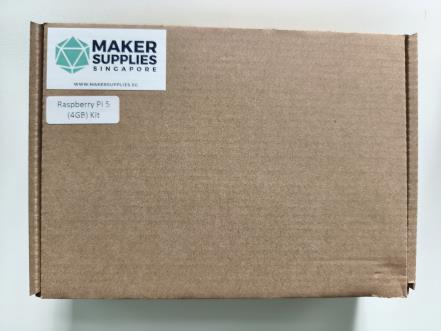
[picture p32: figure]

01 Plates Qty: 2 plates | 02 Dupont Jumper Wire Set Qty: 1 set | 03 Raspberry Pi 5 (4 GB) Kit Qty: 1 kit
04 TT DC Gear Motor Kit (4 motors with wheels and hardware) Qty: 1 kit | 05 Wireless Mouse and Keyboard Kit Qty: 1 kit | 06 Simple Encoder Kit Qty: 2 kits

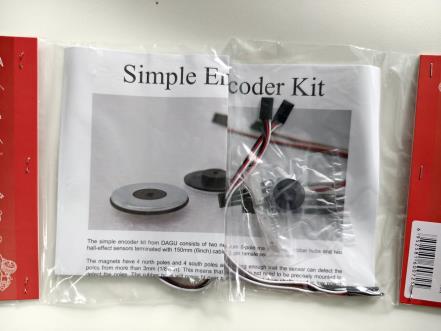
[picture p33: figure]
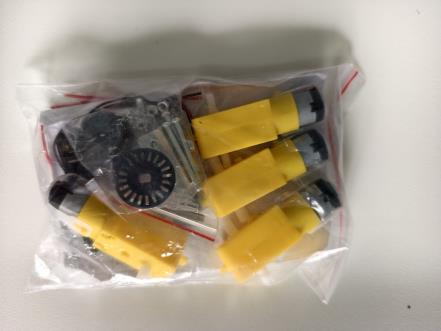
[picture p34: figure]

07 BESTON 4-Slot Smart Battery Chargers Qty: 2 chargers | 08 Arduino Mega 2560 R3 Board Qty: 1 board | 09 Raspberry Pi Camera Module (8 MP, 160° wide-angle) Qty: 1 module

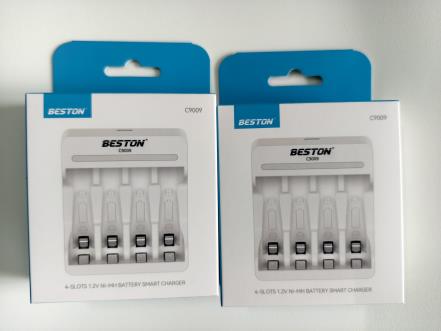
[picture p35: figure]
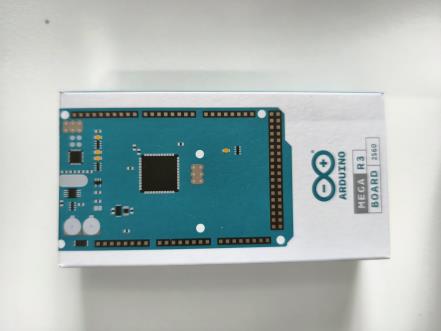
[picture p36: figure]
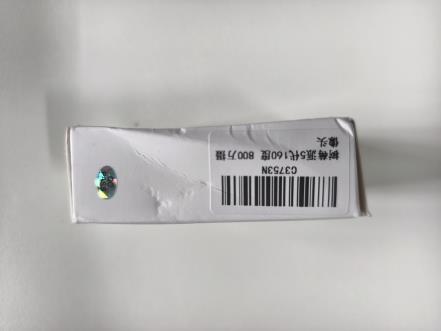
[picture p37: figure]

10 HDMI Video Capture Card Qty: 1 device | 11 32-in-1 Precision Screwdriver Set Qty: 1 set | 12 Xiaomi Mi Power Bank 3 Ultra Compact (10,000 mAh) Qty: 1 power bank


13 Arduino L293D Motor Driver Shield Qty: 1 board | 14 UK Plug Power Adapter Qty: 1 adapter | 15 Diagonal Cutting Pliers Qty: 1 pair
16 Electronic Components Assortment Qty: 1 set | 17 6 × AA Battery Holder with Leads Qty: 1 holder | 18 Solderless Breadboards (2 full-size and 2 mini) Qty: 4 boards


19 Blue Cable Qty: 1 cable | 20 White Cable Qty: 1 cable | 21 USB-C Multiport Adapter / Hub Qty: 1 adapter


22 BESTON AA 1.2 V 1200 mAh Ni-MH Rechargeable Battery Packs Qty: 2 packs | 23 HC-SR04 Ultrasonic Distance Sensor Module Qty: 1 module


# FINAL INVENTORY CHECKLIST

Tick the box after confirming that the item and recorded quantity are present.

No. | Item | Quantity | Check
1 | Plates | 2 plates | ☐
2 | Dupont Jumper Wire Set | 1 set | ☐
3 | Raspberry Pi 5 (4 GB) Kit | 1 kit | ☐
4 | TT DC Gear Motor Kit (4 motors with wheels and hardware) | 1 kit | ☐
5 | Wireless Mouse and Keyboard Kit | 1 kit | ☐
6 | Simple Encoder Kit | 2 kits | ☐
7 | BESTON 4-Slot Smart Battery Chargers | 2 chargers | ☐
8 | Arduino Mega 2560 R3 Board | 1 board | ☐
9 | Raspberry Pi Camera Module (8 MP, 160° wide-angle) | 1 module | ☐
10 | HDMI Video Capture Card | 1 device | ☐
11 | 32-in-1 Precision Screwdriver Set | 1 set | ☐
12 | Xiaomi Mi Power Bank 3 Ultra Compact (10,000 mAh) | 1 power bank | ☐
13 | Arduino L293D Motor Driver Shield | 1 board | ☐
14 | UK Plug Power Adapter | 1 adapter | ☐
15 | Diagonal Cutting Pliers | 1 pair | ☐
16 | Electronic Components Assortment | 1 set | ☐
17 | 6 × AA Battery Holder with Leads | 1 holder | ☐
18 | Solderless Breadboards (2 full-size and 2 mini) | 4 boards | ☐
19 | Blue Cable | 1 cable | ☐
20 | White Cable | 1 cable | ☐
21 | USB-C Multiport Adapter / Hub | 1 adapter | ☐
22 | BESTON AA 1.2 V 1200 mAh Ni-MH Rechargeable Battery Packs | 2 packs | ☐
23 | HC-SR04 Ultrasonic Distance Sensor Module | 1 module | ☐

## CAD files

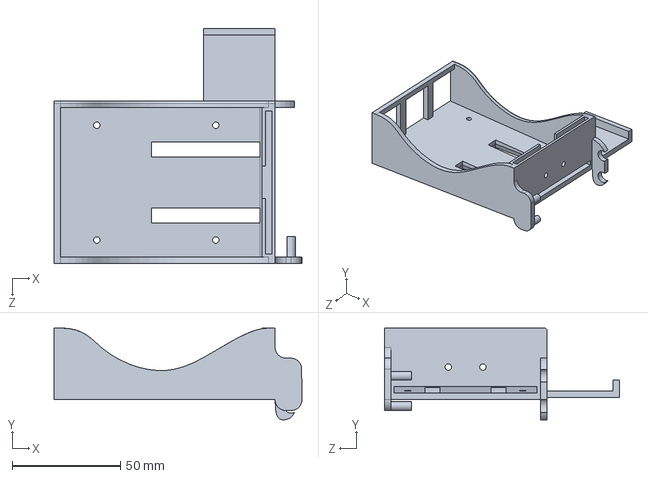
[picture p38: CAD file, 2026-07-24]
hardware/cad/Advanced建模/扑克牌底座.SLDPRT
114.5 x 42.4 x 108.6 mm

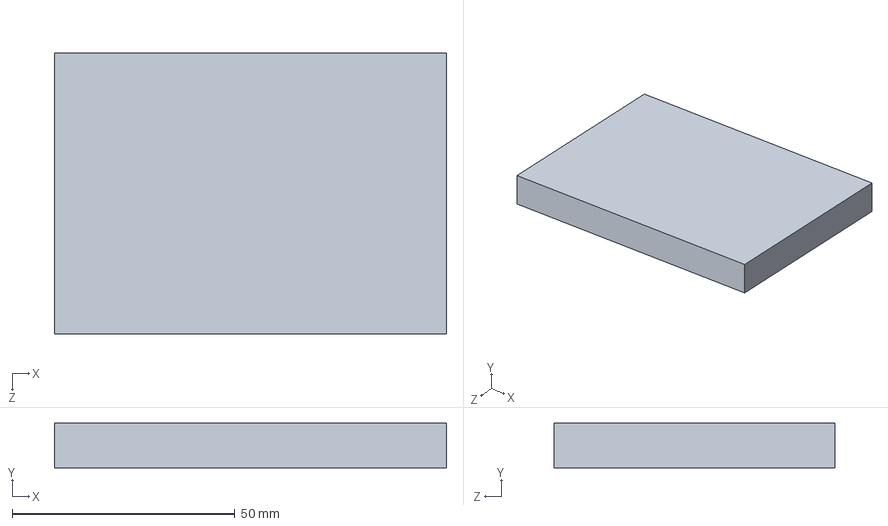
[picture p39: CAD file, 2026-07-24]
hardware/cad/Advanced建模/总装配体_电机在下_v1/扑克牌.SLDPRT
88.0 x 10.0 x 63.0 mm

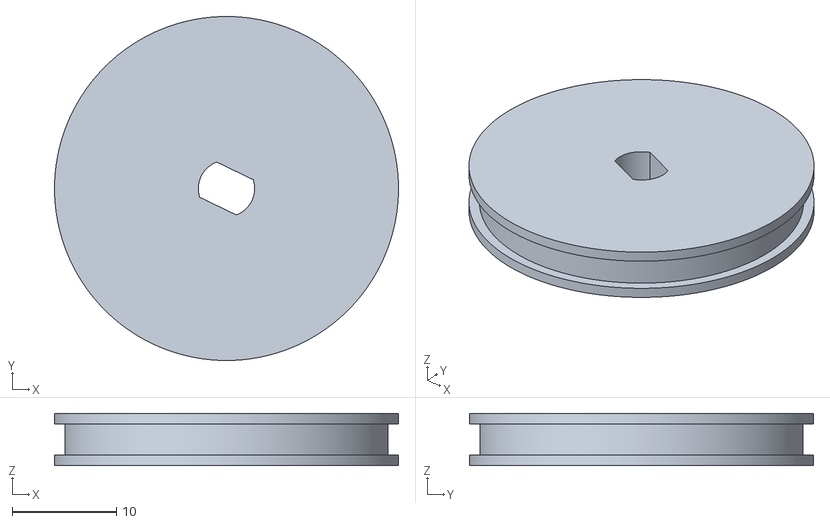
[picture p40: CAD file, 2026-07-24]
hardware/cad/Advanced建模/扑克牌轮_v2.STL
33.0 x 33.0 x 5.00

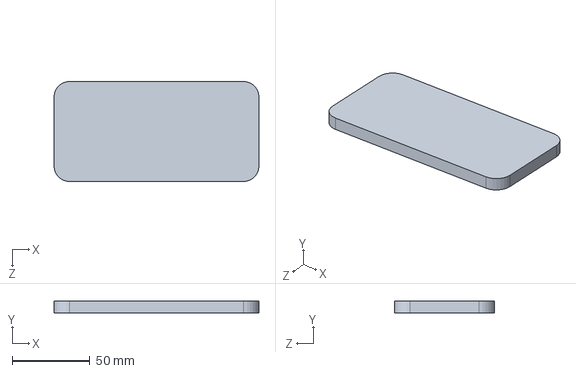
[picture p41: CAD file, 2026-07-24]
hardware/cad/Advanced建模/IP13MINI.SLDPRT
131.5 x 7.65 x 64.2 mm

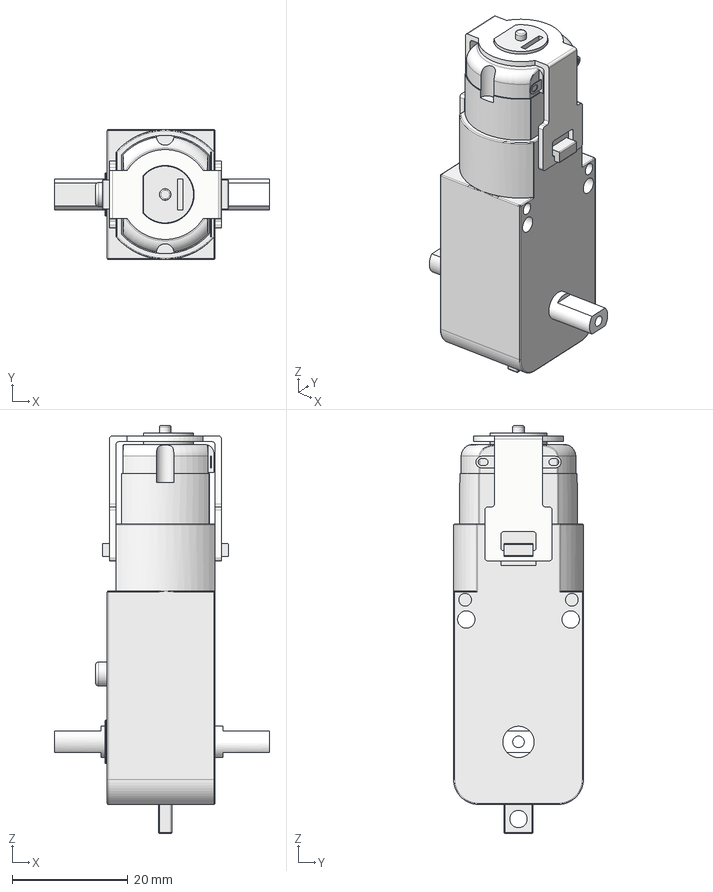
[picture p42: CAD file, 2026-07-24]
hardware/cad/Advanced建模/总装配体_电机在下_v1/YG2900_step.step
37.1 x 22.4 x 70.3 mm

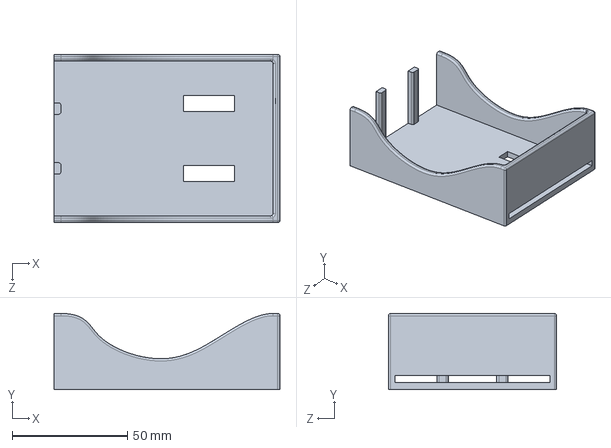
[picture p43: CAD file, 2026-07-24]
hardware/cad/Advanced建模/总装配体_电机在下_v1/扑克牌底座.SLDPRT
98.0 x 33.0 x 73.0 mm

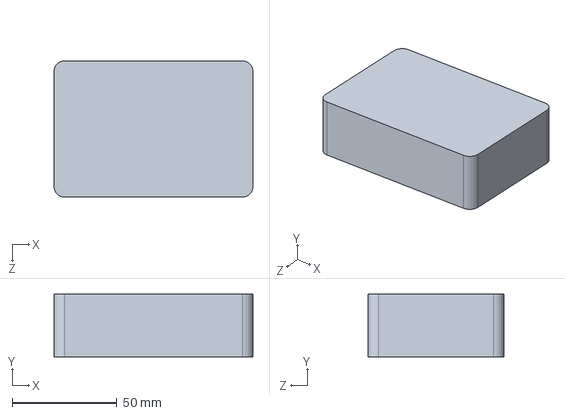
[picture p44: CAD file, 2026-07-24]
hardware/cad/Advanced建模/树莓派.SLDPRT
95.0 x 30.0 x 65.0 mm

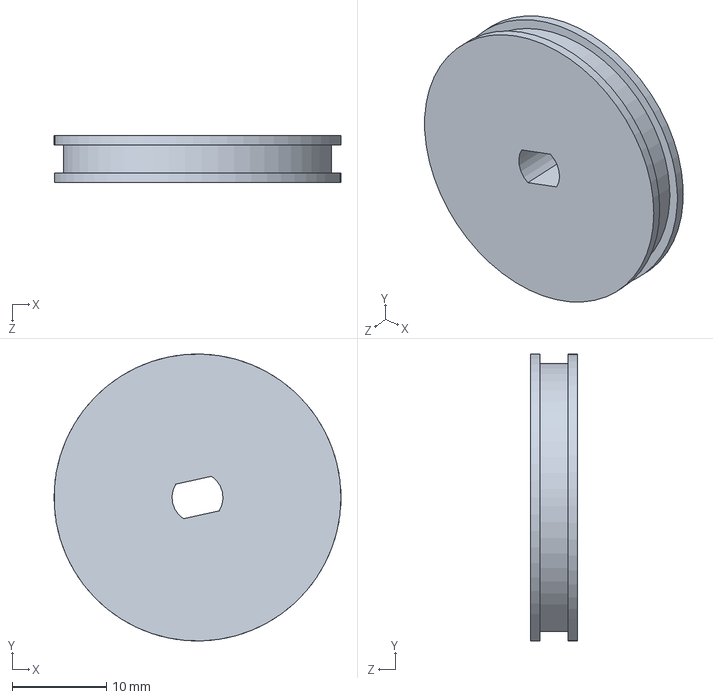
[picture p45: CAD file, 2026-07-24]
hardware/cad/Advanced建模/总装配体_电机在下_v1/扑克牌轮.SLDPRT
30.4 x 30.4 x 5.00 mm

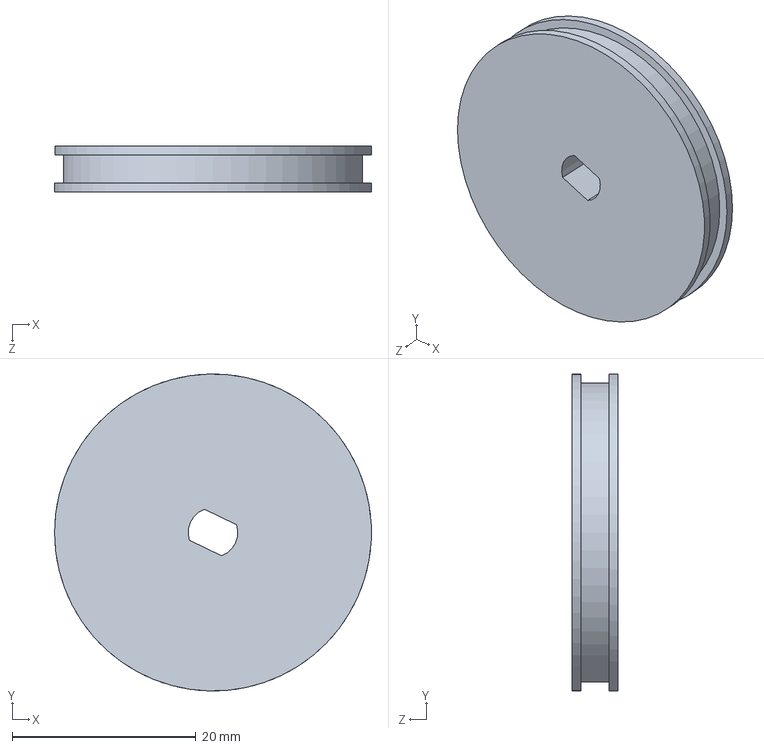
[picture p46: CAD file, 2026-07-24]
hardware/cad/Advanced建模/驱动轮.SLDPRT
34.5 x 34.5 x 5.00 mm

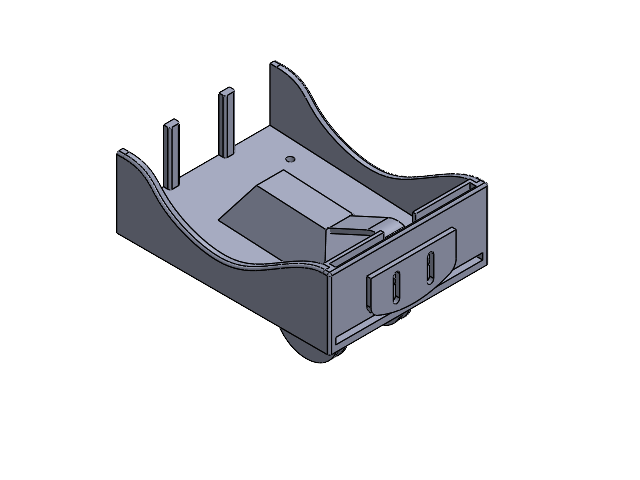
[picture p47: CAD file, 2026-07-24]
hardware/cad/Advanced建模/总装配体_电机在下_v1/总装配体2.SLDASM
扑克牌底座
YG2900_step.step
驱动轮
厚度挡板
压块
扑克牌轮

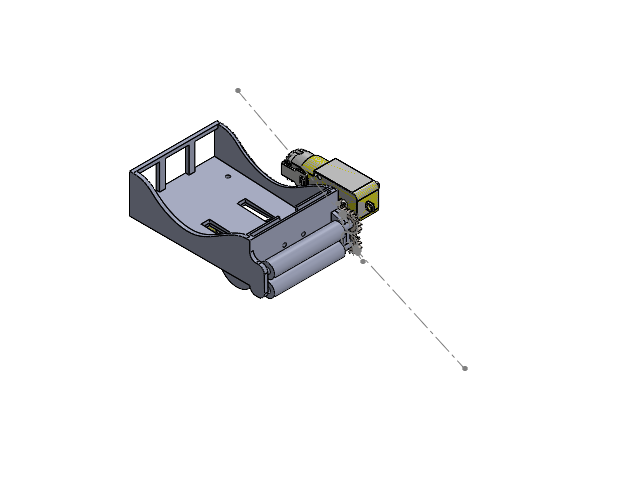
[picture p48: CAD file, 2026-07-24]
hardware/cad/Advanced建模/总装配体2.SLDASM
扑克牌底座
YG2900_step.step x 2
驱动轮
厚度挡板
零件1 x 2
spur gear_gb x 3
零件2^总装配体2
扑克牌轮

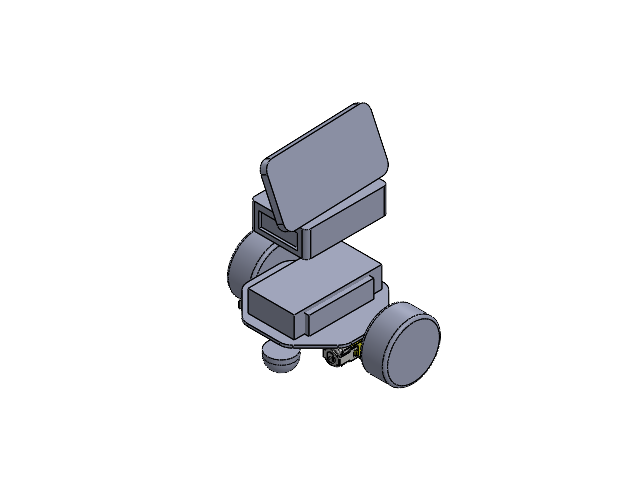
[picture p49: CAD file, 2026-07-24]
hardware/cad/Advanced建模/总装配体.SLDASM
零件4
YG2900_step.step x 2
树莓派
IP13MINI
车轮^总装配体 x 2
零件6^总装配体
零件7^总装配体
电池仓^总装配体

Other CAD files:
hardware/cad/Advanced建模/总装配体_电机在下_v1/厚度挡板.SLDPRT
hardware/cad/Advanced建模/总装配体_电机在下_v1/压块.SLDPRT
hardware/cad/Advanced建模/总装配体_电机在下_v1/驱动轮.SLDPRT
hardware/cad/Advanced建模/厚度挡板.SLDPRT
hardware/cad/Advanced建模/spur gear_gb_齿轮.STL
hardware/cad/Advanced建模/spur gear_gbx2.STL
hardware/cad/Advanced建模/压块.SLDPRT
hardware/cad/Advanced建模/厚度挡板_v2.STL
hardware/cad/Advanced建模/手机支架.SLDPRT
hardware/cad/Advanced建模/手机支架.STL
hardware/cad/Advanced建模/扑克牌底座_v3.STL
hardware/cad/Advanced建模/扑克牌底座v3.1.STL
hardware/cad/Advanced建模/扑克牌轮.SLDPRT
hardware/cad/Advanced建模/零件1.SLDPRT
hardware/cad/Advanced建模/零件1x2.STL
hardware/cad/Advanced建模/零件2^总装配体2.STL
hardware/cad/Advanced建模/零件2^总装配体2_v2.STL
hardware/cad/Advanced建模/零件4.SLDPRT
hardware/cad/Advanced建模/驱动轮.STL
hardware/cad/Advanced建模/驱动轮_v2.STL
hardware/cad/Advanced建模/驱动轮_v3.STL

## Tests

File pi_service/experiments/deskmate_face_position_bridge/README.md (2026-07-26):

# DeskMate-Advance YuNet 人脸位置桥接

这是一个电脑端隔离实验。它调用根目录 Git submodule
`subrepos/DeskMate-Advance` 的正式摄像头与人脸模型接口：

- `poker_dealer.io.camera.OpenCVCamera` 独占读取 DroidCam MJPEG；
- `OpenCvFaceIdentityAdapter` 使用 YuNet 检测和 SFace 特征模型；
- 本实验只发布人脸框、中心偏移和置信度，不保存画面或人脸特征；
- 5059 同时提供带框 MJPEG 预览，JPEG 编码限频并在独立线程中运行；
- 同一进程内的桥接线程直接读取内存快照，不再通过5059回读；
- 桥接线程不启动转向，只用正式Robotics API续租或停止已有转向。

## 数据链路

```text
手机 DroidCam http://100.93.97.117:4747/video
  -> PC OpenCVCamera（直接 MJPEG）
  -> DeskMate YuNet/SFace
     ├─> PC 5059/api/face/latest + preview_feed（仅对外观察）
     └─> 内存 FaceTurnBridge
          -> Pi /api/robotics/v1/status
          -> Pi /api/robotics/v1/actions
             (face_turn_heartbeat 或 face_turn_stop，每次独立 request_id)
```

Pi 的 `start_robot.sh` 只负责 5000 和正式控制服务，不会启动电脑端
DeskMate模型。电脑端现在只需运行本文件一个进程，不再单独启动
`face_turn_web_bridge.py`。

5059 服务默认采用单实例启动。再次执行相同命令时，新进程只会终止命令行指向
本目录同一个 `deskmate_face_position_server.py`、且端口相同的旧进程；不会终止
其他 Python、5000 主服务或不同端口的实验。调试时可用
`--no-replace-existing` 禁止自动替换。

默认直接读取 `http://100.93.97.117:4747/video`，但只有本进程可以打开该原始地址。
不要在浏览器或DroidCam Windows客户端中同时打开原始流；看画面统一使用
`http://127.0.0.1:5059/preview_feed`。若上游被占用，5059会明确返回
`camera_source_busy:droidcam_single_client_in_use` 并每秒重试，释放上游后无需重启。
确需使用本地虚拟摄像头时可显式传 `--source 1 --backend msmf`，但必须先确认设备
索引和真实画面，不能把“设备成功打开”当作画面可用。

本实验不改 DeskMate submodule 的身份验证配置，而在入口层使用更适合远距离车控的
YuNet 参数：检测阈值 `0.75`、最小人脸边长 `40 px`。可分别通过
`--detector-score-threshold` 和 `--minimum-face-size-px` 覆盖。中心停车门禁仍由
桥接器负责，默认 `offset_x_normalized ±0.30`。

## 首次准备

从 Robitics 根目录初始化第三方子模块：

```powershell
git submodule update --init --recursive
py -3 -m pip install -e .\subrepos\DeskMate-Advance
```

两个 ONNX 模型由 Git LFS 管理。新机器如果没有完成 LFS smudge，模型文件会只是
约 130 字节的文本指针，仓库虽然能克隆但模型一定无法加载。安装 Git LFS 后执行：

```powershell
git -C .\subrepos\DeskMate-Advance lfs pull
```

然后用 `FaceIdentityConfig.verify_assets()` 或本目录单元测试核对模型 SHA-256。
当前固定模型哈希为：

- YuNet：`8f2383e4dd3cfbb4553ea8718107fc0423210dc964f9f4280604804ed2552fa4`
- SFace：`0ba9fbfa01b5270c96627c4ef784da859931e02f04419c829e83484087c34e79`

## 无电机探测

先启动 Pi 的 5000 服务，然后在电脑执行有限帧探测：

```powershell
cd C:\Users\32126\Desktop\Robitics
py -3 .\pi_service\experiments\deskmate_face_position_bridge\deskmate_face_position_server.py --probe-frames 10
```

它只打印最后一帧 JSON 后退出，不向 Pi 发送控制请求。

## 单进程持续运行并接入J/L/状态机

电脑终端一：

```powershell
cd C:\Users\32126\Desktop\Robitics
py -3 .\pi_service\experiments\deskmate_face_position_bridge\deskmate_face_position_server.py --source http://100.93.97.117:4747/video --port 5059 --pi-url http://100.80.46.54:5000
```

浏览器检查：

```text
http://127.0.0.1:5059/api/face/latest
http://127.0.0.1:5059/preview_feed
```

端口 5000 的正式控制台会从当前操作电脑的 `127.0.0.1:5059` 加载独立的
“电脑端人脸检测”卡片。绿色框是当前用于控制判断的主脸，黄色竖线是
`face_turn_web_bridge.py` 的中心门禁（默认 `offset_x_normalized ±0.30`），
蓝色竖线是画面中心。状态栏同时显示 YuNet 原始检测数、可用框数和主脸偏移。
如果用另一台电脑或手机打开 5000 页面，它的 `127.0.0.1` 不会指向运行模型的
电脑，因此该卡片会显示离线，但不会影响树莓派相机、路线识别或电机安全逻辑。

无需第二个Windows终端。启动时会精确结束同工作区残留的独立
`face_turn_web_bridge.py`，避免双心跳。随后可由操作者在5000网页按M，再按J/L；
状态机也可调用正式的 `face_turn_start`。内嵌桥接器不会开始转向；它只对
已经由 J/L 启动的 `FACE_CENTER_TURN` 续租，并在人脸居中后发送 STOP。

调试时可用 `--disable-pi-bridge` 只运行推理和5059观察，不向Pi发送任何动作。

## 验证

```powershell
py -3 -m unittest discover -s .\pi_service\experiments\deskmate_face_position_bridge -p "test_*.py" -v
git diff --check -- .gitmodules .\pi_service\experiments\deskmate_face_position_bridge
```

单元测试和有限帧探测只证明代码、模型资源与视频读取链路可运行，不证明真车已经
按人脸完成原地转向。

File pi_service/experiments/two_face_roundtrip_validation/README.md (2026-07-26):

# Two-face roundtrip validation

Purpose: validate the pure route-memory sequence used by the formal end-line
tracker: outbound white-line following, face 1, the opposite-facing white-line
landmark, face 2, final white-line alignment, and an explicitly armed return.

Safety boundary: the tests import only the pure planner. They do not import the
camera, controller, Arduino, Flask service, or any motor-capable runner.

Entry command:

```powershell
py -3 -m unittest discover -s pi_service/experiments/two_face_roundtrip_validation -p "test_*.py" -v
```

Output: unittest transition assertions only.

Validation: both LEFT and RIGHT sweeps must mirror correctly; an incorrect
landmark type must be rejected; return following must remain separately armed.

Promotion criterion: integration in `robot_web/routes/end_line/tracker.py`
must preserve the M gate, heartbeat timeout for face turns, local timeout for
white-line turns, and explicit STOP behavior.

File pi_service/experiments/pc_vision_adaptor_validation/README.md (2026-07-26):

# PC vision adaptor validation (default route mode)

This is the default autonomous route mode for the current green-floor course.
It moves the expensive HSV green-field, red-band, skeleton, and junction work
to the desktop PC.  The Raspberry Pi retains the only M1/M2 control path:

`camera -> Pi near-field scan -> Pi M-key gate -> controller.set_direct_drive -> Arduino`

The desktop may only send one of `SLOW_DOWN`, `TURN_WINDOW_ARMED`,
`BRAKE_NOW`, `PIVOT_REQUEST`, `REVERSE_REQUEST`, or `CLEAR_ARM` to
`/api/vision-adaptor/event`.
It cannot submit PWM and it cannot bypass the M-key gate.  Events must carry a
fresh camera sequence/time and the shared token; old/out-of-order events are
rejected.  If an armed remote session becomes stale, the Pi stops rather than
driving blindly.

### Fixed two-band course timing

The PC reconstructs red fragments into physical layers with a generous Y
cluster tolerance, so left/right fish-eye skew does not make one red band look
like two.  One early band means `SLOW_DOWN`.  When two layers have been seen
and the first leaves, the remaining turn band owns the final timing: at 50%
of image height it emits one `BRAKE_NOW` pulse, then Pi creeps; at 84% of image
height it emits one `PIVOT_REQUEST`; if it exits after reaching 60% but before
the pivot trigger, it emits one `REVERSE_REQUEST`.  Pi fixes the duration and
PWM of all three actions locally.

The first visible red band also pre-authorizes the turn band: its brake/pivot
thresholds become 35%/70% of frame height rather than 50%/84%.  This is an
earlier reaction, not a low-PWM slowdown.  During `SLOW_DOWN`,
`TURN_WINDOW_ARMED`, and after the brake pulse Pi keeps `straight_pwm=85`, but
uses a 260 correction gain and 0.015 deadband for tighter line locking.

## Run

On the Pi, the normal `start_robot.sh` now starts `pc_vision_adaptor` by
default and still begins paused.  Open port 5000 and press **M** only after the
preview is healthy.  On the PC run:

```bash
cd pi_service/experiments/pc_vision_adaptor_validation
python3 pc_slow_analyzer.py --pi-url http://100.80.46.54:5000 --token "$ROBOT_PC_ADAPTOR_TOKEN"
```

For a no-motion transport/overlay check, append `--max-frames 1`; it uploads
one annotated image then exits.  The full command runs continuously.

Set the same `ROBOT_PC_ADAPTOR_TOKEN` in the Pi service environment and on the
PC.  Leave it empty only on an isolated lab network.  The PC now posts a
complete annotated JPEG to port 5000: PC masks/geometry/red-layer state and
cyan Pi fast-scan marks appear in the normal route-preview panel.  If PC
output is older than three seconds the panel falls back to the Pi-only overlay.
This does **not** claim physical turning has been validated.

## Tests

```bash
python3 -m unittest test_protocol test_fast_line test_red_band_planner -v
```

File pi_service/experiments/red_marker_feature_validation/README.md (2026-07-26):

# 红带特征对比实验

此目录只比较视觉特征，不修改或启动主循迹程序。

对一张包含红带的 BGR 图像，脚本比较：

- `R`：裸红色通道；
- `red_excess = R - max(G, B)`：红色优势；
- `gray_minus_g = gray - G`：灰度亮度减绿色通道。

红带的参考标签仅用于离线量化，由 HSV 红色范围生成；运行时不依赖该标签。

```bash
python3 analyze_red_features.py --image /path/to/frame.jpg
```

输出每个特征在红带/非红带区域的分位数、中位间隔和最佳单阈值平衡准确率。

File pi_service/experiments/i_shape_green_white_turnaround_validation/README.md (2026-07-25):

# 绿地白线 I 型掉头验证

本目录只替换 I 型扫描线算法的图像分割：用 HSV 检出绿地中的白胶带。
主线追踪、横线预判、掉头状态机与 PWM 控制复用
`i_shape_scanline_turnaround_validation`，不修改原白底黑线实验。

5000 启动入口：

```bash
cd /home/g11/Desktop/pi_service
./run_green_white_scanline_i_console.sh
```

视觉默认暂停；网页按 `M` 才允许 M1/M2 行驶。

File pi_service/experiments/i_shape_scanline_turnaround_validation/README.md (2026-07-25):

# Scanline I-shape turnaround validation

This new isolated experiment does not modify `robot_web`, the main autonomous
route, or the third-party skeleton detector. It uses a near-anchored connected
component plus fixed scanlines: narrow vertical tape rows form the driving line;
a lower row whose tape width suddenly grows is an endpoint bar, never a left or
right branch to follow.

Preview only:

```bash
/home/g11/Desktop/pi_service/experiments/i_shape_scanline_turnaround_validation/run_pi_scanline_i_preview.sh
```

Open `http://<Pi-IP>:5058`. For the motor test, first stop the main route and
restart only the controller:

```bash
cd /home/g11/Desktop/pi_service
ROBOT_ENABLE_AUTONOMOUS_ROUTE=0 ./start_robot.sh
/home/g11/Desktop/pi_service/experiments/i_shape_scanline_turnaround_validation/run_pi_scanline_i_drive.sh
```

The drive script uses straight `120`, fixed right pivot `R=-200/L=+200`, and a
minimum pivot of `2.5 s`; it logs visual confidence, endpoint width/position,
PWM request/acknowledgement, Arduino output telemetry, and scene/line changes
to `pi_service/logs/i_shape_scanline_turnaround/latest.jsonl`.

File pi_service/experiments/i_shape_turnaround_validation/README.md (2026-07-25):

# I-shape turnaround validation

This folder is isolated from the main autonomous route program. Its default is
the current white-floor / black-tape camera setup (`config.dark_line.json`).

- `run_pi_i_turnaround_preview.sh`: vision only; browse `http://<Pi-IP>:5057`.
- `run_pi_control_chain_right_pivot_probe.sh`: first physical M1/M2 test. It sends only `R=+200, L=-200` for three seconds; it never opens a camera and never touches M3/M4.
- `run_pi_i_turnaround_drive.sh`: the I-route test, fixed at straight `120`, right pivot `R=+200/L=-200`, and a minimum pivot time of `2.5 s`.

Before either motor script, stop the 5000 process that was launched with
`--enable-autonomous-route`, then launch the isolated controller with
`cd /home/g11/Desktop/pi_service && ROBOT_ENABLE_AUTONOMOUS_ROUTE=0 ./start_robot.sh`.
Both motor scripts reject a status response that still has an in-process
autonomous route available: merely pausing it is not sufficient for this
isolated test.

Run the right-pivot probe with the wheels raised first, then in a clear low-speed
area.  Confirm physically that the right wheel moves forward, the left wheel
moves backward, and the chassis pivots right.  The JSONL records request/ack,
latest `/api/status` motor output, and Arduino reply; these telemetry values do
not replace physical confirmation.

The planner follows the long longitudinal stem, confirms a terminal transverse bar for several frames, pivots in one fixed direction for at least the calibrated 180-degree time, then accepts only a long non-transverse line to end the pivot. A pivot timeout stops the motors. Per-frame events are appended to `pi_service/logs/i_turnaround_validation/latest.jsonl`; each includes route state, transverse-bar position, requested/acknowledged PWM, latest Arduino output telemetry, and camera/route-change hints.

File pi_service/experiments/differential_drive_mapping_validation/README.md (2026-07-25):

# Differential drive mapping validation

This isolated test verifies whether the Arduino channels labelled `M1=right` and `M2=left` actually drive the physical right and left wheel groups. It does not open the camera, run vision, plan a route, or operate the card mechanism.

Run on the Pi:

```bash
/home/g11/Desktop/pi_service/experiments/differential_drive_mapping_validation/run_pi_differential_drive_mapping_test.sh
```

The sequence is deliberately short:

1. `right=0`, `left=180` for 5 seconds;
2. stop for one second;
3. `right=180`, `left=0` for 5 seconds;
4. final stop.

Lift the drive wheels or leave clear space. `Ctrl+C` sends `/api/stop`. The result is logged to `/home/g11/Desktop/pi_service/logs/differential_drive_mapping/latest.log`.

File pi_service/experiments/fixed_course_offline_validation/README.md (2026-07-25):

# 固定绿布路线：离线节点回放

该实验只读取视频或 JPG 帧目录，输出路线、横线、节点编号和模拟停车状态；不会连接树莓派、Arduino 或电机。

```powershell
python .\pi_service\experiments\fixed_course_offline_validation\offline_node_replay.py `
  --source .\data\captures\your-session `
  --output-video .\artifacts\offline-node-replay.mp4 `
  --output-jsonl .\artifacts\offline-node-replay.jsonl
```

默认每个确认到的节点在横线到达画面 72% 高度时进入模拟停车，保持 2 秒后继续。输出只代表离线回放，不代表实车已验证。

也可以直接运行：

```powershell
.\pi_service\experiments\fixed_course_offline_validation\run_offline_node_replay.ps1 `
  -Source .\data\captures\your-session
```

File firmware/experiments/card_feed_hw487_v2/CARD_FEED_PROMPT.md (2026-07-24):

# HW-487 卡牌送牌检测 V2：后续开发提示词

将下面内容复制给 Codex，要求只在本文件夹内修改：

```text
你正在维护 `C:\Users\32126\Desktop\Robitics\firmware\card_feed_hw487_v2\card_feed_hw487_v2.ino`。
只修改这个子文件夹，绝不覆盖 `firmware\single_motor_m2_test` 或 `firmware\motor_bridge` 中的原文件。

目标：为 Arduino Mega + AFMotor V1/L293D 的单电机送牌机构做稳定的 HW-487 闭环送牌。

当前硬件：
- 送牌电机接 Motor Shield M2。
- HW-487 槽型光电传感器：S -> Mega D22，+ -> 5V，GND -> GND。
- 可选舵机：信号线 D23，独立 5V 供电，必须与 Mega 共地。
- APDS-9960 如仍连接：SDA -> D20，SCL -> D21；它不是本版本送牌检测的主传感器。

期望控制语义：
1. 电机只低速、小步送牌，不允许持续高速把多张牌一起拉出。
2. HW-487 遮光表示牌进入检测槽；光束恢复表示牌尾已完全离开检测槽。
3. 只有“遮光 -> 恢复光束”才计为一张牌完全通过。
4. 停机后的惯性可能带出下一张牌：若它也完整通过，应单独计数，并从它离开的时刻重新等待 1 秒。
5. 牌仍在检测槽时，不得启动下一次送牌。
6. 任意时刻串口 `0` 或 `STOP` 必须立即停止电机；`1` 启动自动送牌。

当前已知问题：
- 送牌机构可能一次带出多张牌，因此优先确保单张、可解释的检测，再逐步调参。
- 单个 HW-487 无法区分多张牌紧贴且始终遮光的情况；不要把连续遮光误报成多张。
- PWM 不是线性速度：过低会停转，过高会带出多张。当前主送牌速度约 180，检测槽通过速度约 150，必须基于实测调整。

工作方式：
- 先阅读现有状态机、串口命令和顶部可调参数。
- 每次修改后说明状态转换和可调参数。
- 保留电机反转保护、串口急停和无命令超时停车。
- 未经明确要求，不删除现有 APDS、舵机或手动控制命令；可以将无关功能禁用但要说明原因。
- 给出 Arduino IDE 可直接上传的代码；如本机没有 arduino-cli，明确说明未进行实际编译/硬件验证。
```

## V2 基线

`card_feed_hw487_v2.ino` 从 `firmware/single_motor_m2_test/single_motor_m2_test.ino` 复制而来。后续所有卡牌检测试验仅在本目录进行。

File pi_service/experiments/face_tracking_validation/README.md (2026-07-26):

# 人脸转向桥接与历史隔离验证

本目录保留早期5058 MediaPipe纯观测实验，但正式车控不再使用该检测器。当前唯一车控
检测器是相邻目录 `deskmate_face_position_bridge/deskmate_face_position_server.py`
调用的DeskMate YuNet/SFace。正式运行时，该文件同时内嵌本目录可复用的
`FaceTurnBridge`，直接读取内存快照并转换成Pi正式动作API的心跳和停车。

## 树莓派运行

先确保主服务的相机预览可访问，并在当前 Python 环境安装 `mediapipe`，再运行：

```bash
cd /home/g11/Desktop/pi_service/experiments/face_tracking_validation
python3 -m unittest test_face_detector -v
./run_pi_face_probe.sh
```

浏览器打开：`http://127.0.0.1:5058`。

## 唯一的人脸转向链路

只保留这一套车控链路：电脑上的 `deskmate_face_position_server.py` 使用
DeskMate YuNet/SFace做唯一一次推理；
`deskmate_face_position_server.py` 内嵌的桥接线程在网页或状态机已经启动J/L转向后，
通过正式的 `/api/robotics/v1/status` 和 `/api/robotics/v1/actions` 向Pi发送
`face_turn_heartbeat` 或 `face_turn_stop`。每次心跳使用独立 `request_id`，
确保Pi的幂等缓存不会吞掉后续续租。
历史5058探测程序不参与电机控制，也不会和YuNet/SFace同时向Pi发动作。

当前车控人脸摄像头为 `http://100.93.97.117:4747/video`。先在一个终端启动检测：

```powershell
cd C:\Users\32126\Desktop\Robitics
py -3 .\pi_service\experiments\deskmate_face_position_bridge\deskmate_face_position_server.py --source http://100.93.97.117:4747/video --port 5059 --pi-url http://100.80.46.54:5000
```

不再需要第二个终端或独立桥接进程。此后在5000网页先按M，再按J或L；状态机也可用
`face_turn_start` 动作进入相同状态。只有 Pi 已进入 `FACE_CENTER_TURN` 时桥接才会工作：
人脸未居中时持续 `HEARTBEAT`，人脸居中后发送 `STOP`。检测流或网络异常时不续租，Pi 会按安全超时停车。

数据地址为 `http://127.0.0.1:5059/api/face/latest`，字段包括 `detected`、`offset_x`、
归一化偏移、框尺寸和置信度。正 `offset_x` 表示人脸在画面右侧，负值表示左侧。

## 电脑端双相机综合分析

电脑会并行分析 Pi 相机和手机 IP Webcam；两路偏移均保留，综合结果选择当前人脸框更大的
主观测，**不会错误地平均两个相机的像素偏移**。手机与电脑需在同一局域网：

```powershell
py -3 multi_camera_face_position_server.py `
  --pi-source http://100.80.46.54:5000/video_feed `
  --phone-source http://10.50.77.86:8080/video `
  --port 5060
```

浏览器打开 `http://127.0.0.1:5060/` 可并列观看两个带检测框的画面；
`http://10.50.77.205:5060/api/faces/latest` 是供程序读取的 JSON。`sources.pi` 与 `sources.phone`
是各自原始检测；`fused` 是选择出的主观测和选择原因。若未来要算真实空间坐标，需要额外完成
双相机标定。

## 怎么测“最远可检出距离”

1. 面向镜头站立，从近到远每次移动 0.5 米；不要让人脸偏向或被遮挡。
2. 每个距离保持约 5 秒，记录是否连续绿框、页面的“近 5 秒检出率”、框宽（px）和耗时。
3. `runtime_logs/face_probe.jsonl` 保存每帧 `detected`、框宽/面积、中心坐标和处理时间。
4. 将“连续检出率明显下降前的最远距离”作为探索结果；不要把框宽直接当作精确距离。

旧的 `face_track_turn.py` 直接检测并控车，与本链路重复，已移除，避免两个进程同时对 Pi 发人脸转向命令。

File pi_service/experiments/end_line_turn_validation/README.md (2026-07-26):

# 单白线红终点带验证

当前场地只使用一条纵向白胶带，以及两端各一条独立的红色横向终点带。

本实验只验证：沿白线行驶、确认红带、在红带进入画面下部时停车。它不包含 T 字、骨架、横线选路、双红带距离计时、PC 慢分析、180 度掉头或 90 度转向。

红带从白线掩膜中隔离：白线控制使用 HSV 低饱和亮色；终点带使用 `R - max(G,B)`。

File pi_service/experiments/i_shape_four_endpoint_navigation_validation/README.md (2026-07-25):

# 工字形四端点：原地转向调度验证

这是一个纯 Python、不开相机和电机的状态机实验。它实现的赛道规则是：

- 小车只沿中间竖线行驶；
- 到上/下交叉点后，原地转 90° 面朝端点；
- **不沿横杆前进或倒车**；
- 面朝端点后由未来的执行器调用 M3/M4 发牌；
- 去同一交叉点另一端时，经由朝向竖线的两个连续 90° 转向，不使用 180° 定时转向；
- 去另一交叉点时，先转回竖线，再沿竖线行驶。

视觉适配层需要提供：

- `junction_detected`：骨架 junction / 横杆确认；
- `forward_line_detected`：转动后，预期方向的白线在画面底部中央连续出现；
- `deal_complete`：M3/M4 动作完成回报。

运行离线测试：

```bash
cd /home/g11/Desktop/pi_service/experiments/i_shape_four_endpoint_navigation_validation
python3 -m unittest -v test_four_endpoint_planner
```

## 5000 接入验证

新的可选路线模式只验证第一个目标 `[1]`：沿竖线通过上横杆的既有掉头触发位置后，原地左转 90°，重捕横杆方向白线后停车。它不会在横杆刚进入画面时转弯：优先等红带到达底部并消失；无红带时才以“白横杆确认后的竖线丢失”作为后备。它只在按 `M` 后控制 M1/M2，**不会调用 M3/M4 发牌**，也不会沿横杆行驶。

```bash
cd /home/g11/Desktop/pi_service
bash ./run_four_endpoint_pivot_validation_console.sh
```

打开 `http://127.0.0.1:5000`，画面状态应依次显示：

`FOLLOW_STEM → STOP_AT_JUNCTION → PIVOT_TO_HEADING → DEAL_CARD`

现有 I 型 180° 掉头入口不变；该模式是单独的 `route-mode`，同一时刻只能运行其中一个。

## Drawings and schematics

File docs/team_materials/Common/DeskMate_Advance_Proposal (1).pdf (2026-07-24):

SWS3009 · ADVANCE PROPOSAL

# DeskMate

# Team 11 — Loss Hunters

## Wang Tianqi · Chen Zengchun · Gu Songtao · Lin Ziqi

DESKMATE | GROUP 11 · LOSS HUNTERS

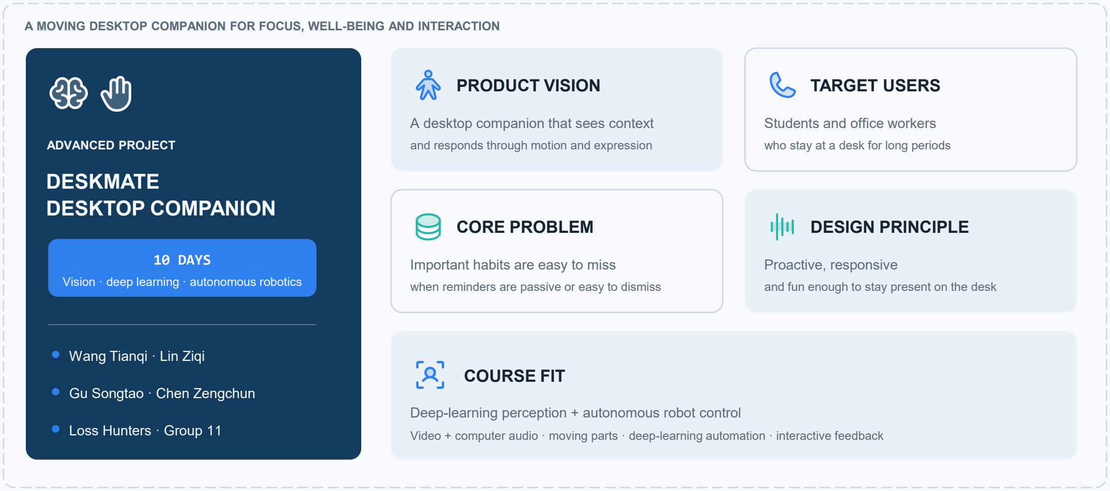
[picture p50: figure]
ADVANCED PROJECT; DESKMATE DESKTOP COMPANION; 10 DAYS; Wang Tianqi · Lin Ziqi; Gu Songtao · Chen Zengchun; Loss Hunters · Group 11; PRODUCT VISION; A desktop companion that sees context; TARGET USERS; Students and office workers; who stay at a desk for long periods; CORE PROBLEM; Important habits are easy to miss; DESIGN PRINCIPLE; Proactive, responsive; COURSE FIT

A MOVING DESKTOP COMPANION FOR FOCUS, WELL-BEING AND INTERACTION

Vision · deep learning · autonomous robotics and responds through motion and expression

when reminders are passive or easy to dismiss

and fun enough to stay present on the desk

Deep-learning perception + autonomous robot control

Video + computer audio · moving parts · deep-learning automation · interactive feedback

PRODUCT OVERVIEW | HEALTH · FOCUS · COMPANIONSHIP

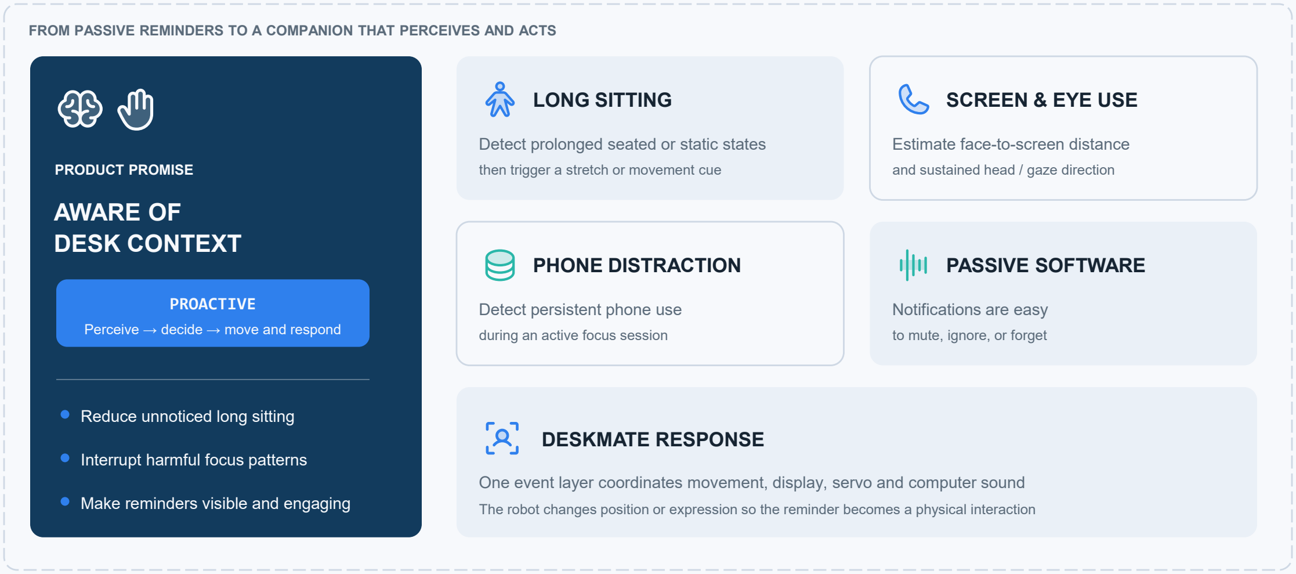
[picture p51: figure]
PRODUCT PROMISE; AWARE OF DESK CONTEXT; PROACTIVE; Perceive → decide → move and respond; Reduce unnoticed long sitting; Interrupt harmful focus patterns; Make reminders visible and engaging; LONG SITTING; then trigger a stretch or movement cue; SCREEN & EYE USE; Estimate face-to-screen distance; and sustained head / gaze direction; PHONE DISTRACTION; Detect persistent phone use; during an active focus session; PASSIVE SOFTWARE; Notifications are easy; to mute, ignore, or forget; DESKMATE RESPONSE

FROM PASSIVE REMINDERS TO A COMPANION THAT PERCEIVES AND ACTS

Detect prolonged seated or static states

One event layer coordinates movement, display, servo and computer sound

The robot changes position or expression so the reminder becomes a physical interaction

# CORE EXPERIENCE

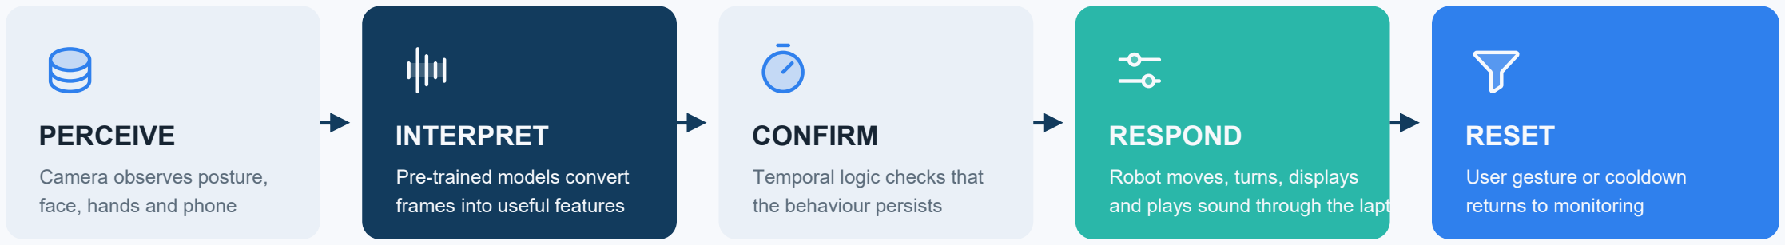
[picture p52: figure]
PERCEIVE; Camera observes posture,; face, hands and phone; INTERPRET; Pre-trained models convert; frames into useful features; CONFIRM; Temporal logic checks that; the behaviour persists; RESPOND; Robot moves, turns, displays; and plays sound through the laptop; RESET; User gesture or cooldown; returns to monitoring
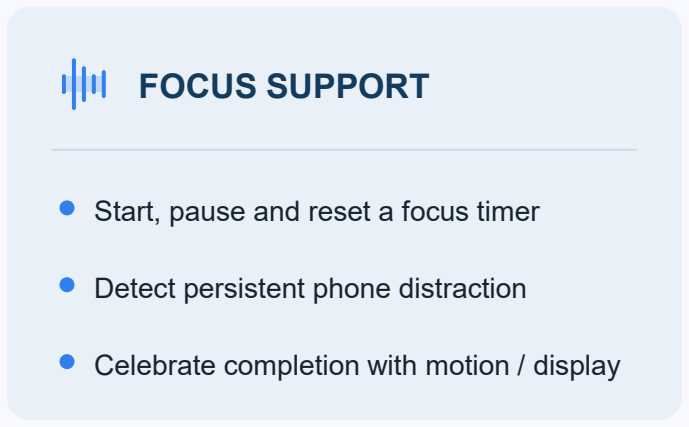
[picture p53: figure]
FOCUS SUPPORT; Start, pause and reset a focus timer; Detect persistent phone distraction

Celebrate completion with motion / display

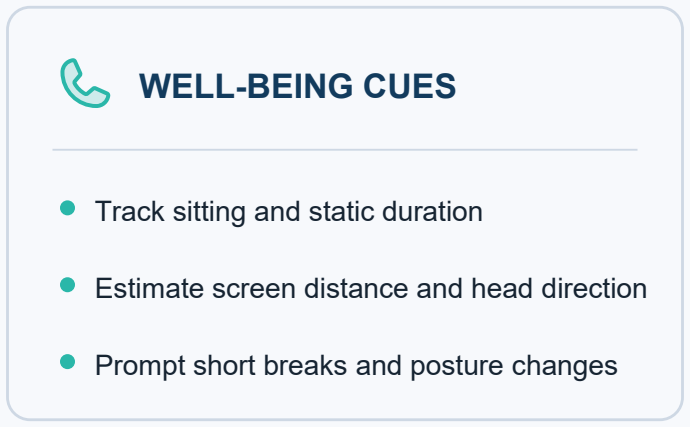
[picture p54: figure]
WELL-BEING CUES; Track sitting and static duration; Prompt short breaks and posture changes

Estimate screen distance and head direction

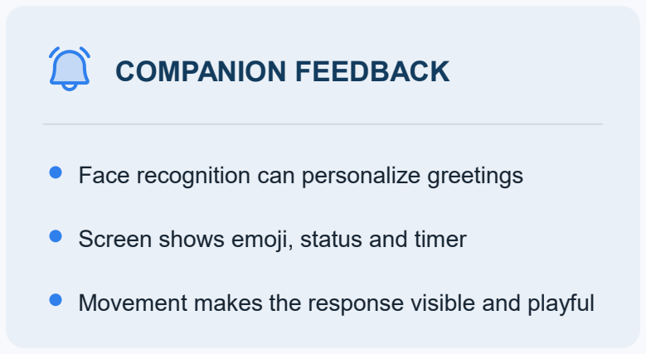
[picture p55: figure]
COMPANION FEEDBACK; Face recognition can personalize greetings; Screen shows emoji, status and timer

Movement makes the response visible and playful

Video and laptop audio drive decisions; motion, display and sound close the interaction loop.

# SYSTEM ARCHITECTURE

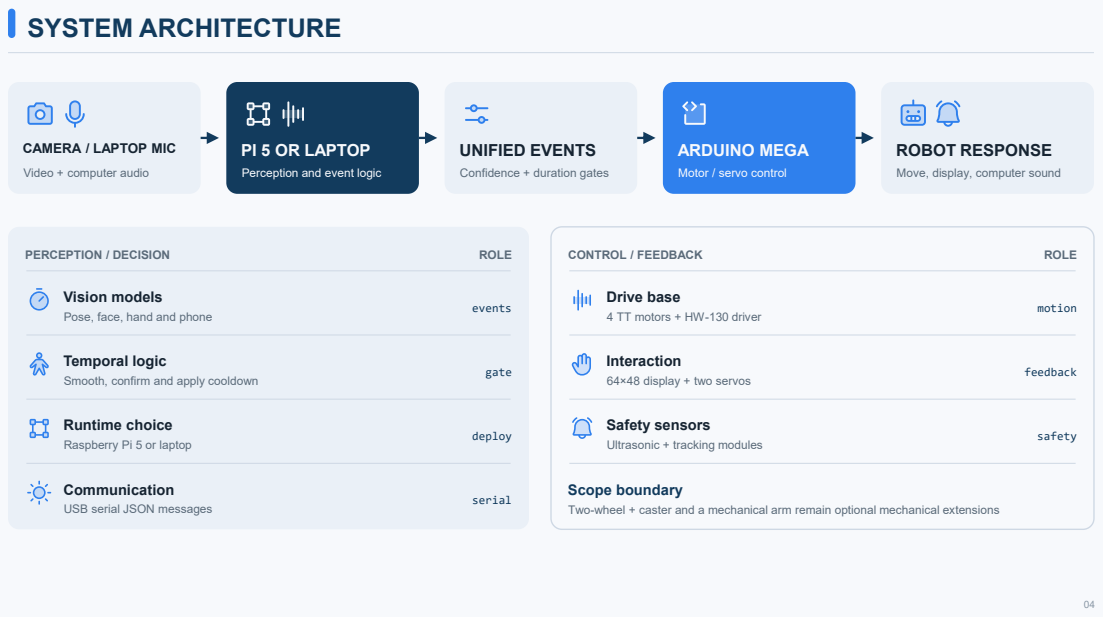
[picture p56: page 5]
UNIFIED EVENTS; ARDUINO MEGA; ROBOT RESPONSE; PERCEPTION / DECISION; ROLE; Vision models; events; Temporal logic; gate; Runtime choice; deploy; Communication; serial; CONTROL / FEEDBACK; Drive base; motion; Interaction; feedback; Safety sensors; safety; Scope boundary

CAMERA / LAPTOP MIC

PI 5 OR LAPTOP

Video + computer audio

Perception and event logic

Confidence + duration gates

Motor / servo control

Move, display, computer sound

Pose, face, hand and phone

4 TT motors + HW-130 driver

Smooth, confirm and apply cooldown

64×48 display + two servos

Raspberry Pi 5 or laptop

Ultrasonic + tracking modules

USB serial JSON messages

Two-wheel + caster and a mechanical arm remain optional mechanical extensions

## PRE-TRAINED

### POSE

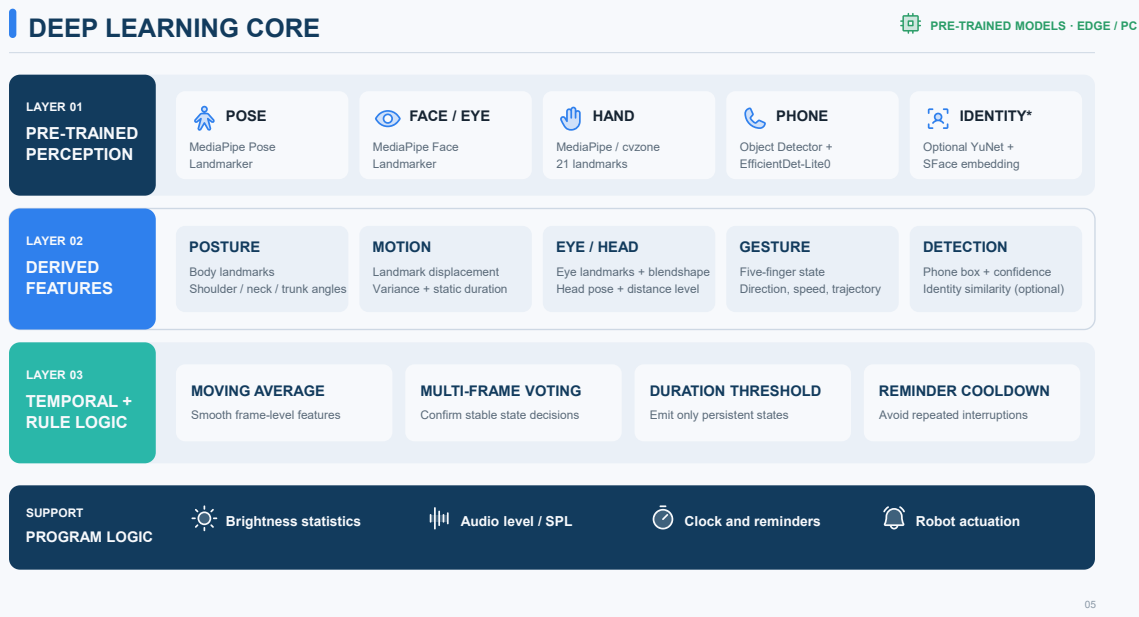
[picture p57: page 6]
DEEP LEARNING CORE; PRE-TRAINED MODELS · EDGE / PC; LAYER 01; PERCEPTION; MediaPipe Pose Landmarker; FACE / EYE; MediaPipe Face Landmarker; HAND; MediaPipe / cvzone 21 landmarks; PHONE; Object Detector + EfficientDet-Lite0; IDENTITY*; Optional YuNet + SFace embedding; LAYER 02; DERIVED FEATURES; POSTURE; MOTION; EYE / HEAD; GESTURE; DETECTION; LAYER 03; TEMPORAL + RULE LOGIC; MOVING AVERAGE; DURATION THRESHOLD; REMINDER COOLDOWN; SUPPORT; PROGRAM LOGIC; Brightness statistics; Audio level / SPL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

Body landmarks
Shoulder / neck / trunk angles

Landmark displacement
Variance + static duration

Eye landmarks + blendshape
Head pose + distance level

Five-finger state
Direction, speed, trajectory

Phone box + confidence
Identity similarity (optional)

MULTI-FRAME VOTING

Smooth frame-level features

Confirm stable state decisions

Emit only persistent states

Avoid repeated interruptions
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

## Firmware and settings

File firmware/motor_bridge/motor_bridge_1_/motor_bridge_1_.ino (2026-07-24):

#include <Arduino.h>
#include <AFMotor.h>
#include <ctype.h>
#include <stdlib.h>
#include <string.h>
#include <Wire.h>
#include <Servo.h>

// ============================================================
// Raspberry Pi -> Arduino motor bridge  +  IMU  +  Speed PID
//
// Serial protocol (9600 baud, one command per line):
//
//   Motor control:
//     M,m1,m2,m3,m4\n         raw drive PWM (-255..255); M3/M4 fields ignored
//     FEED,signedPwm,timeMs\n  run M3 with adjustable power, direction and duration
//     DEAL,signedPwm,timeMs\n  run M4 with adjustable power, direction and duration
//
//   Speed control (left/right drive):
//     V,leftPPS,rightPPS\n    target speed in pulses/sec (signed)
//                              PID overrides M2 / M1 in M commands
//
//   PID tuning:
//     KP,value\n  KI,value\n  KD,value\n
//
//   Queries:
//     STOP | S                 stop M1/M2 + disable speed control
//     IMU                      query Euler angles
//     SPD                      query wheel speeds + PID state
//     OUT                      query actual PWM applied to M1..M4
//     US                       query the front ultrasonic distance
//     SV,angle                 set SG90 servo target angle (0..180)
//     SVF,angle                move SG90 at its mechanical maximum speed
//     SVP                      query current SG90 angle
//     SVD,direction            manual servo direction (-1, 0, 1)
//     SVC,speed,acceleration   set servo motion limits (degrees/s, degrees/s^2)
//
//   Active motor mapping:
//     M1 = right-side vehicle drive
//     M2 = left-side vehicle drive
//     M3 = adjustable timed card-feed motor
//     M4 = adjustable timed dealing motor
//
//   Hall encoders:
//     Pin 18 (INT3) = left drive wheel (M2)
//     Pin 19 (INT2) = right drive wheel (M1)
//     8-pole magnet → 4 pulses per revolution
//
//   Speed unit: pulses/second (pps).
//     Convert m/s → pps:  pps = 4 * (m/s) / (π * wheel_diameter_m)
// ============================================================

AF_DCMotor motor1(1);
AF_DCMotor motor2(2);
AF_DCMotor motor3(3);
AF_DCMotor motor4(4);

// AFMotor accepts PWM values from 0 to 255.
const int MOTOR_COMMAND_LIMIT = 255;

// If no valid drive command is received within this interval, release M1/M2.
// Card motors have their own deterministic state and timer.
const unsigned long COMMAND_TIMEOUT_MS = 1000;

// While the robot is stationary, publish a clear serial heartbeat so that a
// connected Serial Monitor can confirm the Arduino is alive and stopped.
const unsigned long STOPPED_REPORT_INTERVAL_MS = 1000;

// Before changing a drive motor from forward to backward, release M1/M2
// briefly to reduce current and mechanical shock.
const unsigned long REVERSE_PAUSE_MS = 80;

// Card mechanism. Signed PWM determines direction: positive is FORWARD and
// negative is BACKWARD. Web controls can therefore adjust each card motor's
// speed, direction and runtime without reflashing the Arduino.
constexpr int DEFAULT_CARD_FEED_PWM = -255;
constexpr int DEFAULT_CARD_DEAL_PWM = 255;
constexpr unsigned long DEFAULT_CARD_FEED_TIME_MS = 5000UL;
constexpr unsigned long DEFAULT_CARD_DEAL_TIME_MS = 1000UL;
constexpr unsigned long MIN_CARD_MOTOR_TIME_MS = 100UL;
constexpr unsigned long MAX_CARD_MOTOR_TIME_MS = 60000UL;

// ============================================================
// One forward-facing ultrasonic sensor.  It stops forward travel only.
//
// Only the front TRIG/ECHO pin pair is used by this firmware.
// ============================================================

constexpr bool ULTRASONIC_BLOCKING_ENABLED = true;
constexpr uint8_t FRONT_TRIG_PIN = 26;
constexpr uint8_t FRONT_ECHO_PIN = 27;

constexpr unsigned long ULTRASONIC_ECHO_TIMEOUT_US = 30000UL;
constexpr unsigned long ULTRASONIC_BETWEEN_SENSORS_MS = 35UL;
// Only the single centre/front sensor is safety active.  A distance at or
// below this threshold blocks forward wheel commands; pivots and reverse are
// intentionally left available.
constexpr float FRONT_STOP_DISTANCE_CM = 1.0F;

float frontDistanceCm = -1.0F;

enum UltrasonicState {
  ULTRASONIC_IDLE,
  ULTRASONIC_TRIGGER_LOW,
  ULTRASONIC_TRIGGER_HIGH,
  ULTRASONIC_WAIT_RISE,
  ULTRASONIC_WAIT_FALL
};

UltrasonicState ultrasonicState = ULTRASONIC_IDLE;
unsigned long ultrasonicPhaseStartUs = 0;
unsigned long ultrasonicEchoRiseUs = 0;
unsigned long lastUltrasonicStartMs = 0;

// ============================================================
// MPU-6500 IMU constants and configuration
// ============================================================

// I2C address (AD0 pin low = 0x68, AD0 pin high = 0x69)
const uint8_t MPU_ADDR = 0x68;

// Register addresses
const uint8_t MPU_REG_WHO_AM_I     = 0x75;
const uint8_t MPU_REG_PWR_MGMT_1   = 0x6B;
const uint8_t MPU_REG_GYRO_CONFIG  = 0x1B;
const uint8_t MPU_REG_ACCEL_CONFIG = 0x1C;
const uint8_t MPU_REG_CONFIG       = 0x1A;
const uint8_t MPU_REG_SMPLRT_DIV   = 0x19;
const uint8_t MPU_REG_ACCEL_XOUT_H = 0x3B;
const uint8_t MPU_REG_GYRO_XOUT_H  = 0x43;

// Expected WHO_AM_I response for MPU-6500
const uint8_t MPU_WHO_AM_I_EXPECTED = 0x70;

// IMU timing
const unsigned long IMU_SAMPLE_INTERVAL_MS = 10;   // 100 Hz internal sample rate
const unsigned long IMU_REPORT_INTERVAL_MS = 100;   // 10 Hz report rate to serial

// Complementary filter: higher alpha = more trust in gyro, less in accel
const float COMPLEMENTARY_ALPHA = 0.96f;

// Sensor full-scale ranges (must match register configuration)
const float GYRO_FULL_SCALE_DPS  = 250.0f;   // FS_SEL = 0 => +/-250 deg/s
const float ACCEL_FULL_SCALE_G   = 2.0f;     // AFS_SEL = 0 => +/-2 g

// Conversion: 16-bit signed range / full-scale range
const float GYRO_LSB_PER_DPS  = 32768.0f / GYRO_FULL_SCALE_DPS;   // 131.072
const float ACCEL_LSB_PER_G   = 32768.0f / ACCEL_FULL_SCALE_G;    // 16384.0

// Degrees conversion
// Arduino.h already defines RAD_TO_DEG as a macro on AVR boards.
const float RAD_TO_DEG_FACTOR = 180.0f / PI;

// Gyro calibration: number of stationary samples at startup
const int GYRO_CALIBRATION_SAMPLES = 200;

// ============================================================
// Hall-effect encoder (wheel speed) constants
// ============================================================

// 8-pole magnet ring → 4 full pulses per wheel revolution.
const float PULSES_PER_REVOLUTION = 4.0f;

// Encoder input pins (Arduino Mega external interrupt pins).
const uint8_t ENCODER_LEFT_PIN  = 18;  // INT3 — left drive motor (M2)
const uint8_t ENCODER_RIGHT_PIN = 19;  // INT2 — right drive motor (M1)

// SG90 signal wire.  Power the servo from a suitable 5 V supply with a
// common ground to the Mega; do not power it from the Mega's 5 V pin.
// D22 is reserved for the HW-487 card sensor in the current hardware.
constexpr uint8_t SERVO_PIN = 23;
constexpr int SERVO_CENTER_ANGLE = 90;
constexpr int SERVO_POWER_ON_START_ANGLE = 0;
constexpr unsigned long SERVO_POWER_ON_HOLD_MS = 600UL;
constexpr unsigned long SERVO_UPDATE_INTERVAL_MS = 20;
constexpr unsigned long SERVO_DIRECTION_TIMEOUT_MS = 450;
constexpr float SERVO_DEFAULT_SPEED_DPS = 45.0F;
constexpr float SERVO_DEFAULT_ACCELERATION_DPS2 = 120.0F;
Servo panServo;

// Servo motion is generated on the Arduino, not by bursty browser/serial
// angle updates.  This keeps Q/E motion smooth even when Wi-Fi timing varies.
float servoCurrentAngle = SERVO_CENTER_ANGLE;
float servoTargetAngle = SERVO_CENTER_ANGLE;
float servoVelocityDps = 0.0F;
float servoMaxSpeedDps = SERVO_DEFAULT_SPEED_DPS;
float servoAccelerationDps2 = SERVO_DEFAULT_ACCELERATION_DPS2;
int8_t servoManualDirection = 0;
unsigned long lastServoUpdateMs = 0;
unsigned long lastServoDirectionCommandMs = 0;
int lastServoWrittenAngle = SERVO_CENTER_ANGLE;

// Runs once during setup so the hardware can visibly confirm the servo range.
// Afterwards normal web/serial servo control takes over from the final 0° pose.
void runServoPowerOnSequence() {
  const int sequence[] = {0, 90, 180, 90, 0};
  for (uint8_t i = 0; i < sizeof(sequence) / sizeof(sequence[0]); ++i) {
    panServo.write(sequence[i]);
    delay(SERVO_POWER_ON_HOLD_MS);
  }

  servoCurrentAngle = SERVO_POWER_ON_START_ANGLE;
  servoTargetAngle = SERVO_POWER_ON_START_ANGLE;
  servoVelocityDps = 0.0F;
  lastServoWrittenAngle = SERVO_POWER_ON_START_ANGLE;
}

// Speed is computed from pulse counts at this interval (ms).
const unsigned long SPEED_CALC_INTERVAL_MS = 50;   // 20 Hz

// PID update rate for rear-wheel speed control (ms).
const unsigned long PID_UPDATE_INTERVAL_MS = 50;   // 20 Hz

// PID output limits (PWM).
const float PID_OUTPUT_MIN = 0.0f;
const float PID_OUTPUT_MAX = 255.0f;

// Maximum length of one serial command, including the final '\0'.
const size_t COMMAND_BUFFER_SIZE = 64;

char commandBuffer[COMMAND_BUFFER_SIZE];
size_t commandLength = 0;
bool discardUntilNewline = false;

unsigned long lastValidCommandTime = 0;
bool timeoutStopped = true;

// Last commands after clamping.
int currentMotorCommands[4] = {0, 0, 0, 0};
unsigned long lastStoppedReportTime = 0;
bool cardDealRunning = false;
unsigned long cardDealStartedAt = 0;
unsigned long cardDealDurationMs = DEFAULT_CARD_DEAL_TIME_MS;
bool cardFeedRunning = false;
unsigned long cardFeedStartedAt = 0;
unsigned long cardFeedDurationMs = DEFAULT_CARD_FEED_TIME_MS;

// ============================================================
// MPU-6500 IMU state variables
// ============================================================

// True if the MPU-6500 was detected and initialised successfully.
bool imuPresent = false;

// Timing book-keeping for non-blocking IMU reads.
unsigned long lastImuSampleTime = 0;
unsigned long lastImuReportTime = 0;
unsigned long lastGyroTimestamp = 0;

// Euler angles (degrees).
float roll  = 0.0f;
float pitch = 0.0f;
float yaw   = 0.0f;

// Gyro bias offsets (degrees/second), computed during calibration.
float gyroBiasX = 0.0f;
float gyroBiasY = 0.0f;
float gyroBiasZ = 0.0f;

// ============================================================
// Hall encoder — pulse counting (updated by ISRs)
// ============================================================

// volatile: written in ISR context, read in loop().
volatile unsigned long encoderPulsesLeft  = 0;
volatile unsigned long encoderPulsesRight = 0;

// ============================================================
// Speed control state
// ============================================================

// True when speed control is active for the rear wheels.
bool speedControlEnabled = false;

// Target speeds in pulses per second (signed: + = forward, – = backward).
float targetSpeedLeft  = 0.0f;
float targetSpeedRight = 0.0f;

// Measured speeds (pulses/second).
float currentSpeedLeft  = 0.0f;
float currentSpeedRight = 0.0f;

// PID output: signed PWM values for the rear motors.
int pidOutputLeft  = 0;
int pidOutputRight = 0;

// PID internal state.
float pidIntegralLeft   = 0.0f;
float pidIntegralRight  = 0.0f;
float pidLastErrorLeft  = 0.0f;
float pidLastErrorRight = 0.0f;

// PID gains (tune these!).
float speedKp = 2.0f;
float speedKi = 0.8f;
float speedKd = 0.05f;

// Speed calculation timer.
unsigned long lastSpeedCalcTime = 0;

// Copies of the pulse counters at the previous speed calculation tick.
unsigned long prevPulsesLeft  = 0;
unsigned long prevPulsesRight = 0;

#if 0
int clampMotorCommand(int value) {
  return constrain(value, -MOTOR_COMMAND_LIMIT, MOTOR_COMMAND_LIMIT);
}

int commandDirection(int value) {
  if (value > 0) {
    return 1;
  }
  if (value < 0) {
    return -1;
  }
  return 0;
}

void applyOneMotor(AF_DCMotor &motor, int command) {
  command = clampMotorCommand(command);
  const uint8_t pwm = (uint8_t)abs(command);

  motor.setSpeed(pwm);

  if (command > 0) {
    motor.run(FORWARD);
  } else if (command < 0) {
    motor.run(BACKWARD);
  } else {
    motor.run(RELEASE);
  }
}

void releaseAllMotors() {
  motor1.setSpeed(0);
  motor2.setSpeed(0);
  motor3.setSpeed(0);
  motor4.setSpeed(0);

  motor1.run(RELEASE);
  motor2.run(RELEASE);
  motor3.run(RELEASE);
  motor4.run(RELEASE);

  for (int i = 0; i < 4; ++i) {
    currentMotorCommands[i] = 0;
  }

  // Reset speed-control state so a fresh V command is required.
  speedControlEnabled   = false;
  targetSpeedLeft       = 0.0f;
  targetSpeedRight      = 0.0f;
  pidIntegralLeft       = 0.0f;
  pidIntegralRight      = 0.0f;
  pidLastErrorLeft      = 0.0f;
  pidLastErrorRight     = 0.0f;
  pidOutputLeft         = 0;
  pidOutputRight        = 0;
}

#endif
#include "motor_control.h"

bool startCardFeed(int pwm, unsigned long durationMs) {
  if (cardFeedRunning) {
    return false;
  }
  applyOneMotor(motor3, pwm);
  currentMotorCommands[2] = pwm;
  cardFeedStartedAt = millis();
  cardFeedDurationMs = durationMs;
  cardFeedRunning = true;
  return true;
}

void updateCardFeed() {
  if (!cardFeedRunning ||
      millis() - cardFeedStartedAt < cardFeedDurationMs) {
    return;
  }
  applyOneMotor(motor3, 0);
  currentMotorCommands[2] = 0;
  cardFeedRunning = false;
  Serial.println(F("FEED:DONE"));
}

bool startCardDeal(int pwm, unsigned long durationMs) {
  if (cardDealRunning) {
    return false;
  }
  applyOneMotor(motor4, pwm);
  currentMotorCommands[3] = pwm;
  cardDealStartedAt = millis();
  cardDealDurationMs = durationMs;
  cardDealRunning = true;
  return true;
}

void updateCardDeal() {
  if (!cardDealRunning ||
      millis() - cardDealStartedAt < cardDealDurationMs) {
    return;
  }
  applyOneMotor(motor4, 0);
  currentMotorCommands[3] = 0;
  cardDealRunning = false;
  Serial.println(F("DEAL:DONE"));
}

// ============================================================
// MPU-6500 I2C helper functions
// ============================================================

// Write a single byte to an MPU-6500 register.
// Returns true on success (I2C ACK received).
bool writeMPURegister(uint8_t reg, uint8_t value) {
  Wire.beginTransmission(MPU_ADDR);
  Wire.write(reg);
  Wire.write(value);
  return Wire.endTransmission() == 0;
}

// Burst-read `count` bytes starting from `startReg` into `buffer`.
// Returns true if all requested bytes were received.
bool readMPURegisters(uint8_t startReg, uint8_t *buffer, size_t count) {
  Wire.beginTransmission(MPU_ADDR);
  Wire.write(startReg);
  if (Wire.endTransmission(false) != 0) {
    return false;
  }

  size_t received = Wire.requestFrom(MPU_ADDR, count);
  if (received != count) {
    return false;
  }

  for (size_t i = 0; i < count; ++i) {
    buffer[i] = Wire.read();
  }
  return true;
}

// ============================================================
// MPU-6500 sensor fusion
// ============================================================

// Calibrate the gyroscope by averaging stationary samples.
// The robot MUST remain still during this call (~400 ms).
void calibrateGyro() {
  float sumX = 0.0f, sumY = 0.0f, sumZ = 0.0f;

  for (int i = 0; i < GYRO_CALIBRATION_SAMPLES; ++i) {
    uint8_t buffer[6];
    if (readMPURegisters(MPU_REG_GYRO_XOUT_H, buffer, 6)) {
      int16_t gx = (int16_t)((buffer[0] << 8) | buffer[1]);
      int16_t gy = (int16_t)((buffer[2] << 8) | buffer[3]);
      int16_t gz = (int16_t)((buffer[4] << 8) | buffer[5]);
      sumX += gx;
      sumY += gy;
      sumZ += gz;
    }
    delay(2);
  }

  // Convert average raw value to degrees/second.
  gyroBiasX = (sumX / GYRO_CALIBRATION_SAMPLES) / GYRO_LSB_PER_DPS;
  gyroBiasY = (sumY / GYRO_CALIBRATION_SAMPLES) / GYRO_LSB_PER_DPS;
  gyroBiasZ = (sumZ / GYRO_CALIBRATION_SAMPLES) / GYRO_LSB_PER_DPS;
}

// Initialise the MPU-6500: wake up, configure ranges, calibrate gyro.
// Returns true if the sensor is present and ready.
bool initMPU6500() {
  // 1. Verify chip identity.
  uint8_t whoAmI = 0;
  if (!readMPURegisters(MPU_REG_WHO_AM_I, &whoAmI, 1)) {
    return false;
  }
  if (whoAmI != MPU_WHO_AM_I_EXPECTED) {
    return false;
  }

  // 2. Wake up from sleep (write 0 to PWR_MGMT_1).
  if (!writeMPURegister(MPU_REG_PWR_MGMT_1, 0x00)) {
    return false;
  }
  delay(10);

  // 3. Gyro config: FS_SEL = 0 (+/-250 dps), no self-test.
  if (!writeMPURegister(MPU_REG_GYRO_CONFIG, 0x00)) {
    return false;
  }

  // 4. Accel config: AFS_SEL = 0 (+/-2 g), no self-test.
  if (!writeMPURegister(MPU_REG_ACCEL_CONFIG, 0x00)) {
    return false;
  }

  // 5. DLPF_CFG = 3 (44.8 Hz gyro bandwidth, 44.8 Hz accel bandwidth
  //    at 1 kHz internal sample rate).
  if (!writeMPURegister(MPU_REG_CONFIG, 0x03)) {
    return false;
  }

  // 6. Sample rate divider = 0 => 1 kHz / (1+0) = 1 kHz internal rate.
  if (!writeMPURegister(MPU_REG_SMPLRT_DIV, 0x00)) {
    return false;
  }

  // 7. Gyro bias calibration (robot must be stationary).
  calibrateGyro();

  lastGyroTimestamp = millis();
  return true;
}

// Burst-read 14 bytes from ACCEL_XOUT_H:
//   accel X/Y/Z (6), temperature (2), gyro X/Y/Z (6)
// Returns true on successful read.
bool readRawIMU(int16_t *accel, int16_t *gyro) {
  uint8_t buffer[14];
  if (!readMPURegisters(MPU_REG_ACCEL_XOUT_H, buffer, 14)) {
    return false;
  }

  accel[0] = (int16_t)((buffer[0]  << 8) | buffer[1]);   // AX
  accel[1] = (int16_t)((buffer[2]  << 8) | buffer[3]);   // AY
  accel[2] = (int16_t)((buffer[4]  << 8) | buffer[5]);   // AZ

  // buffer[6..7] = temperature, skipped

  gyro[0]  = (int16_t)((buffer[8]  << 8) | buffer[9]);   // GX
  gyro[1]  = (int16_t)((buffer[10] << 8) | buffer[11]);  // GY
  gyro[2]  = (int16_t)((buffer[12] << 8) | buffer[13]);  // GZ

  return true;
}

// Complementary filter: fuse accelerometer gravity vector with
// gyroscope angular velocity integration.
// \param dt  Time delta in seconds since previous sample.
void updateAttitude(int16_t *accelRaw, int16_t *gyroRaw, float dt) {
  // Convert raw to physical units.
  float ax = accelRaw[0] / ACCEL_LSB_PER_G;
  float ay = accelRaw[1] / ACCEL_LSB_PER_G;
  float az = accelRaw[2] / ACCEL_LSB_PER_G;

  float gx = (gyroRaw[0] / GYRO_LSB_PER_DPS) - gyroBiasX;
  float gy = (gyroRaw[1] / GYRO_LSB_PER_DPS) - gyroBiasY;
  float gz = (gyroRaw[2] / GYRO_LSB_PER_DPS) - gyroBiasZ;

  // Roll / pitch from the accelerometer gravity vector.
  float accelRoll  = atan2(ay, az) * RAD_TO_DEG_FACTOR;
  float accelPitch = atan2(-ax, sqrt(ay * ay + az * az)) * RAD_TO_DEG_FACTOR;

  // Gyro-only integration step.
  float gyroRoll  = roll  + gx * dt;
  float gyroPitch = pitch + gy * dt;
  float gyroYaw   = yaw   + gz * dt;

  // Complementary filter — roll and pitch.
  roll  = COMPLEMENTARY_ALPHA * gyroRoll  +
          (1.0f - COMPLEMENTARY_ALPHA) * accelRoll;
  pitch = COMPLEMENTARY_ALPHA * gyroPitch +
          (1.0f - COMPLEMENTARY_ALPHA) * accelPitch;

  // Yaw: gyro-only integration (drifts without magnetometer).
  yaw = gyroYaw;
}

// Print current Euler angles to serial.
void printIMU() {
  Serial.print(F("IMU,"));
  Serial.print(roll, 2);
  Serial.print(',');
  Serial.print(pitch, 2);
  Serial.print(',');
  Serial.println(yaw, 2);
}

// ============================================================
// Hall encoder interrupt service routines
// ============================================================

// Left rear encoder (pin 18, INT3).
void encoderLeftISR() {
  encoderPulsesLeft++;
}

// Right rear encoder (pin 19, INT2).
void encoderRightISR() {
  encoderPulsesRight++;
}
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
void loop() {
  while (Serial.available() > 0) {
    const char received = (char)Serial.read();

    if (discardUntilNewline) {
      if (received == '\n') {
        discardUntilNewline = false;
        commandLength = 0;
      }
      continue;
    }

    if (received == '\n') {
      commandBuffer[commandLength] = '\0';

      // Remove a possible Windows-style carriage return.
      if (commandLength > 0 &&
          commandBuffer[commandLength - 1] == '\r') {
        commandBuffer[commandLength - 1] = '\0';
      }

      executeLine(commandBuffer);
      commandLength = 0;
      continue;
    }

    if (commandLength < COMMAND_BUFFER_SIZE - 1) {
      commandBuffer[commandLength++] = received;
    } else {
      commandLength = 0;
      discardUntilNewline = true;
      releaseDriveMotors();
      timeoutStopped = true;
      Serial.println(F("ERR:COMMAND_TOO_LONG"));
    }
  }

  // Keep sensor sampling independent from remote-control command timing.
  updateUltrasonic();
  updateServoMotion();
  updateCardFeed();
  updateCardDeal();

  // An obstacle may appear after a previously safe forward command.  Stop it
  // here instead of waiting for the next remote heartbeat.
  const char *activeBlockReason = forwardBlockReason(
    currentMotorCommands[0], currentMotorCommands[1],
    currentMotorCommands[2], currentMotorCommands[3]
  );
  if (activeBlockReason != nullptr) {
    stopForObstacle(activeBlockReason);
  }

  if (!timeoutStopped &&
      millis() - lastValidCommandTime > COMMAND_TIMEOUT_MS) {
    releaseDriveMotors();
    timeoutStopped = true;
    Serial.println(F("TIMEOUT:STOP"));
  }

  // ---- Non-blocking IMU sampling ----
  if (imuPresent) {
    unsigned long now = millis();

    // Read raw IMU data at the configured sample rate.
    if (now - lastImuSampleTime >= IMU_SAMPLE_INTERVAL_MS) {
      int16_t accelRaw[3], gyroRaw[3];
      if (readRawIMU(accelRaw, gyroRaw)) {
        float dt = (now - lastGyroTimestamp) / 1000.0f;
        // Reject unreasonably large gaps (e.g. motor-reversal pause).
        if (dt > 0.0f && dt < 0.5f) {
          updateAttitude(accelRaw, gyroRaw, dt);
        }
        lastGyroTimestamp = now;
      }
      lastImuSampleTime = now;
    }
  }

  // ---- Speed measurement + PID speed control ----
  {
    unsigned long now = millis();
    if (now - lastSpeedCalcTime >= SPEED_CALC_INTERVAL_MS) {
      float dt = (now - lastSpeedCalcTime) / 1000.0f;
      if (dt > 0.0f && dt < 1.0f) {
        updateSpeedMeasurements();

        if (speedControlEnabled) {
          updateSpeedPID(dt);
        }
      }
      lastSpeedCalcTime = now;
    }
  }

  reportStoppedState();
}

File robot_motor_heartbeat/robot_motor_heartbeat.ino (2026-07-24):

#include <AFMotor.h>
#include <ctype.h>
#include <stdlib.h>
#include <string.h>

// =====================================================
// 电机定义
// M1 = 左前
// M2 = 右前
// M3 = 左后
// M4 = 右后
// =====================================================

AF_DCMotor motor1(1);
AF_DCMotor motor2(2);
AF_DCMotor motor3(3);
AF_DCMotor motor4(4);

// =====================================================
// 可调参数
// =====================================================

// 正常 PWM 范围
const int MIN_SPEED = 0;
const int MAX_SPEED = 255;

// 启动瞬间使用的 PWM
const int START_BOOST_SPEED = 255;

// 启动冲击持续时间，单位 ms
// 建议从 200 开始，最多先不要超过 350
const unsigned long START_BOOST_TIME = 220;

// 电机已经转起来后，允许使用的最低巡航 PWM
const int MIN_HOLD_SPEED = 150;

// 转弯时内侧轮速度比例
const float TURN_RATIO = 0.70;

// 超过该时间没有收到新命令，自动停车
const unsigned long COMMAND_TIMEOUT = 1000;

// =====================================================
// 串口状态
// =====================================================

char commandBuffer[32];
uint8_t commandLength = 0;

unsigned long lastCommandTime = 0;
bool timeoutStopped = true;

// 当前运行状态
char currentAction = 'S';
int currentSpeed = 0;

// =====================================================
// 基础电机控制
// =====================================================

void setLeftSpeed(int speedValue) {
  speedValue = constrain(speedValue, 0, 255);

  motor1.setSpeed(speedValue);
  motor3.setSpeed(speedValue);
}

void setRightSpeed(int speedValue) {
  speedValue = constrain(speedValue, 0, 255);

  motor2.setSpeed(speedValue);
  motor4.setSpeed(speedValue);
}

void setBothSpeed(int leftSpeed, int rightSpeed) {
  setLeftSpeed(leftSpeed);
  setRightSpeed(rightSpeed);
}

void leftForward() {
  motor1.run(FORWARD);
  motor3.run(FORWARD);
}

void leftBackward() {
  motor1.run(BACKWARD);
  motor3.run(BACKWARD);
}

void rightForward() {
  motor2.run(FORWARD);
  motor4.run(FORWARD);
}

void rightBackward() {
  motor2.run(BACKWARD);
  motor4.run(BACKWARD);
}

void stopAll() {
  motor1.run(RELEASE);
  motor2.run(RELEASE);
  motor3.run(RELEASE);
  motor4.run(RELEASE);
}

// =====================================================
// 速度处理
// =====================================================

int getHoldSpeed(int requestedSpeed) {
  requestedSpeed = constrain(requestedSpeed, MIN_SPEED, MAX_SPEED);

  if (requestedSpeed == 0) {
    return 0;
  }

  if (requestedSpeed < MIN_HOLD_SPEED) {
    return MIN_HOLD_SPEED;
  }

  return requestedSpeed;
}

// =====================================================
// 启动增压
// =====================================================

void startWithBoost(
  int leftTargetSpeed,
  int rightTargetSpeed,
  bool leftDirectionForward,
  bool rightDirectionForward
) {
  leftTargetSpeed = getHoldSpeed(leftTargetSpeed);
  rightTargetSpeed = getHoldSpeed(rightTargetSpeed);

  // 先停车，避免直接反转产生巨大冲击
  stopAll();
  delay(50);

  // 设置方向
  if (leftDirectionForward) {
    leftForward();
  } else {
    leftBackward();
  }

  if (rightDirectionForward) {
    rightForward();
  } else {
    rightBackward();
  }

  // 启动瞬间使用高 PWM
  int leftBoost = leftTargetSpeed > 0 ? START_BOOST_SPEED : 0;
  int rightBoost = rightTargetSpeed > 0 ? START_BOOST_SPEED : 0;

  setBothSpeed(leftBoost, rightBoost);
  delay(START_BOOST_TIME);

  // 启动后降到目标巡航速度
  setBothSpeed(leftTargetSpeed, rightTargetSpeed);
}

// =====================================================
// 各种运动动作
// =====================================================

void moveForward(int speedValue) {
  speedValue = getHoldSpeed(speedValue);

  startWithBoost(
    speedValue,
    speedValue,
    true,
    true
  );
}

void moveBackward(int speedValue) {
  speedValue = getHoldSpeed(speedValue);

  startWithBoost(
    speedValue,
    speedValue,
    false,
    false
  );
}

void turnLeft(int speedValue) {
  speedValue = getHoldSpeed(speedValue);

  int leftSpeed = (int)(speedValue * TURN_RATIO);
  leftSpeed = getHoldSpeed(leftSpeed);

  startWithBoost(
    leftSpeed,
    speedValue,
    true,
    true
  );
}

void turnRight(int speedValue) {
  speedValue = getHoldSpeed(speedValue);

  int rightSpeed = (int)(speedValue * TURN_RATIO);
  rightSpeed = getHoldSpeed(rightSpeed);

  startWithBoost(
    speedValue,
    rightSpeed,
    true,
    true
  );
}

void pivotLeft(int speedValue) {
  speedValue = getHoldSpeed(speedValue);

  startWithBoost(
    speedValue,
    speedValue,
    false,
    true
  );
}

void pivotRight(int speedValue) {
  speedValue = getHoldSpeed(speedValue);

  startWithBoost(
    speedValue,
    speedValue,
    true,
    false
  );
}

void backLeft(int speedValue) {
  speedValue = getHoldSpeed(speedValue);

  int leftSpeed = (int)(speedValue * TURN_RATIO);
  leftSpeed = getHoldSpeed(leftSpeed);

  startWithBoost(
    leftSpeed,
    speedValue,
    false,
    false
  );
}

void backRight(int speedValue) {
  speedValue = getHoldSpeed(speedValue);

  int rightSpeed = (int)(speedValue * TURN_RATIO);
  rightSpeed = getHoldSpeed(rightSpeed);

  startWithBoost(
    speedValue,
    rightSpeed,
    false,
    false
  );
}

// =====================================================
// 执行串口命令
// =====================================================

void executeCommand(char action, int speedValue) {
  action = toupper(action);
  speedValue = constrain(speedValue, MIN_SPEED, MAX_SPEED);

  lastCommandTime = millis();
  timeoutStopped = false;

  // 重复收到相同命令时，只刷新超时时间
  // 避免每 200 ms 都进行一次启动冲击
  if (
    action == currentAction &&
    speedValue == currentSpeed &&
    action != 'S'
  ) {
    return;
  }

  switch (action) {
    case 'F':
      moveForward(speedValue);
      break;

    case 'B':
      moveBackward(speedValue);
      break;

    case 'L':
      turnLeft(speedValue);
      break;

    case 'R':
      turnRight(speedValue);
      break;

    case 'Q':
      pivotLeft(speedValue);
      break;

    case 'E':
      pivotRight(speedValue);
      break;

    case 'Z':
      backLeft(speedValue);
      break;

    case 'C':
      backRight(speedValue);
      break;

    case 'S':
      stopAll();
      speedValue = 0;
      break;

    default:
      stopAll();
      currentAction = 'S';
      currentSpeed = 0;

      Serial.println("ERR:UNKNOWN_COMMAND");
      return;
  }

  currentAction = action;
  currentSpeed = speedValue;

  Serial.print("OK:");
  Serial.print(action);
  Serial.print(",");
  Serial.println(speedValue);
}

// =====================================================
// 解析命令
//
// 命令格式：
// F,180
// B,180
// S,0
// =====================================================

void parseCommand(char *command) {
  if (command[0] == '\0') {
    return;
  }

  char action = command[0];
  int speedValue = 180;

  char *commaPosition = strchr(command, ',');

  if (commaPosition != NULL) {
    speedValue = atoi(commaPosition + 1);
  }

  executeCommand(action, speedValue);
}

// =====================================================
// 初始化
// =====================================================
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

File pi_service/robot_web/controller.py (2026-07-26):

"""Terminal-compatible action state machine and Arduino serial bridge."""
from __future__ import annotations

import threading
import time
from dataclasses import asdict
import json
import os
from pathlib import Path

import serial

from control.card_control import CARD_COMMAND_ACK_TIMEOUT_SECONDS, CardControlMixin
from control.drive_config import (
    Config,
    default_profiles,
    legacy_scalar_profiles,
    normalize_profiles,
)
from control.motor_commands import raw_motor_output, speed_targets
from control.protocol import parse_protocol_line
from control.servo_control import ServoControlMixin

HEARTBEAT_SECONDS = 0.20
DIRECT_DRIVE_SECONDS = 0.05
AUTONOMOUS_DRIVE_LEASE_SECONDS = 0.35
SERVO_TICK_SECONDS = 0.05
CLIENT_TIMEOUT_SECONDS = 0.80
ACTIONS = {"STOP", "F", "SF", "B", "PL", "PR", "SPL", "SPR", "FL", "FR", "BL", "BR"}
# Q/E are steering-servo controls rather than motor profiles.
KEY_ACTIONS = {"w": "F", "slow": "SF", "a": "PL", "d": "PR", "s": "B", "x": "SPL", "c": "SPR"}
class RobotController(CardControlMixin, ServoControlMixin):
    heartbeat_seconds = HEARTBEAT_SECONDS
    client_timeout_seconds = CLIENT_TIMEOUT_SECONDS
    # Compatibility names retained for existing diagnostics.
    _raw = staticmethod(raw_motor_output)
    _speed = staticmethod(speed_targets)
    def __init__(
        self,
        port: str,
        config_path: Path | None = None,
        legacy_config_path: Path | None = None,
        config_store=None,
    ) -> None:
        default_path = Path(__file__).with_name("drive_config.json")
        self.port, self.config_path, self.lock = port, Path(config_path or default_path).expanduser(), threading.RLock()
        # Explicit paths remain the compatibility/testing contract.  The
        # assembled formal service passes the unified store instead.
        self.config_store = config_store if config_path is None else None
        self.legacy_config_path = (
            Path(legacy_config_path).expanduser()
            if legacy_config_path is not None
            else Path(__file__).with_name("robot_config.json") if config_path is None else None
        )
        self.config_io_lock = threading.Lock()
        self.config, migrated_legacy, self.config_source, self.config_error = self._load_config()
        # Existing users already have their tuned values in robot_config.json.
        # Copy them once to the dedicated drive file; never overwrite the old
        # file, and never let ordinary source edits replace the tuned values.
        if migrated_legacy:
            self._save_config()
        self.serial_lock = threading.RLock()
        self.serial = None; self.action = "STOP"; self.held_keys: set[str] = set(); self.last_client_seen = 0.0
        self.direct_drive: tuple[int, int] | None = None
        self.direct_drive_owner: str | None = None
        self.direct_drive_expires_at = 0.0
        self.steering_direction = 0; self.last_steering_seen = 0.0
        self._last_sent_steering_direction: int | None = None
        self._last_steering_sent_at = 0.0
        self._last_sent_servo_limits: tuple[float, float] | None = None
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

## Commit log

2026-07-15 web: add explicit PID controls
2026-07-15 firmware: limit avoidance to front movement
    [motor_bridge_1_.ino]
2026-07-15 firmware: use Arduino sketch folder layout
2026-07-15 pi: parse one-sensor ultrasonic telemetry
2026-07-15 camera: set short exposure after configuration
    [camera.py]
2026-07-15 web: add Arduino reconnect control
2026-07-15 pi: restore hold control and camera baseline
2026-07-15 camera: use BGR capture for correct colors
    [camera.py]
2026-07-15 camera: explicitly convert RGB frames to BGR
2026-07-15 camera: preserve Picamera2 RGB888 OpenCV channel order
2026-07-15 web: add card dashboard and wheel profiles
2026-07-15 pi: make Arduino reconnect serial-safe
2026-07-15 pi: persist wheel configuration across restarts
2026-07-15 web: expose live camera stream metrics
2026-07-15 web: add switchable CSI resolution modes
2026-07-15 safety: set front obstacle threshold to 30cm
2026-07-16 firmware: add web servo control
2026-07-16 web: send servo angle updates immediately
2026-07-16 firmware: set forward obstacle threshold to 10cm
2026-07-16 web: add compact dual camera console
2026-07-16 pi: pass rational framerate to h264 encoder
2026-07-16 web: make highres jpeg frame rate configurable
2026-07-16 pi: make mjpeg camera low latency and configurable
2026-07-16 web: add steering controls and slow forward
2026-07-16 web: smooth steering and add z center key
2026-07-16 web: show camera gimbal direction
2026-07-16 web: calibrate camera direction display
2026-07-16 firmware: tune default drive pwm profiles
2026-07-16 pi: add radial edge color correction
    [app.py, camera.py]
2026-07-16 pi: strengthen mid-radius color correction
    [camera.py]
2026-07-16 web: show live wheel pwm outputs
2026-07-16 firmware: report live motor outputs
2026-07-17 firmware: smooth servo motion on arduino
2026-07-17 firmware: raise default servo speed to 45 dps
2026-07-17 firmware: add fast servo centering
2026-07-17 web: sync live servo orientation telemetry
2026-07-17 web: preserve full camera frame in all layouts
2026-07-24 feat: add M3 M4 car drive camera test
2026-07-24 fix: auto detect Arduino serial device for car test
    [app.py]
2026-07-24 fix: map car drive test to M1 and M2
    [app.py]
2026-07-24 fix: use R for card dealing and restore WASD drive
    [controller.py]
2026-07-24 fix: restore two-output drive motor tuning
2026-07-24 fix: support legacy Arduino card deal protocol
    [app.py, controller.py]
2026-07-24 test: add M3 M4 PWM 200 firmware
2026-07-24 fix: confirm card motor commands over drive channel
    [app.py, controller.py, motor_bridge_1_.ino]
2026-07-24 backup: preserve workspace before repository organization
    [IP13MINI.SLDPRT, YG2900_step.step, spur gear_gb_齿轮.STL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]
2026-07-24 chore: organize repository into deployment and archive areas
    [IP13MINI.SLDPRT, YG2900_step.step, spur gear_gb_齿轮.STL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]
2026-07-24 fix: constrain live line detection to track corridor
2026-07-24 feat: add guarded line-following motor executor
2026-07-24 tune: shorten corner approach and restore pivot power
2026-07-24 tune: increase tracking drive and pivot power
2026-07-24 tune: lower line tracking motor power
2026-07-24 tune: use independent outer correction power
2026-07-24 feat: add proportional visual line steering
2026-07-24 feat: stabilize line control in ground coordinates
2026-07-24 fix: wait for Pi Arduino handshake before tracking
2026-07-24 fix: hold steering through brief path loss
2026-07-24 feat: predict path through camera blind zone
2026-07-24 fix: preserve minimum wheel torque while turning
2026-07-25 fix: wait for Arduino and persist path logs
2026-07-25 feat: log continuous path steering evidence
2026-07-25 test: add isolated constant pwm drive check
2026-07-25 fix: keep marker preview current
2026-07-25 feat: add green white motor tracking launcher
2026-07-25 fix: apply small green course steering errors
2026-07-25 feat: stop inner wheel for sharp path turns
2026-07-25 test: stop inner wheel in differential mapping check
2026-07-25 tune: raise fixed I-turn drive power
2026-07-25 feat: add I-turn control-chain telemetry probe
2026-07-25 fix: pivot sharply with opposing wheel PWM
2026-07-25 feat: add HybridScanlineAnalyzer with skeleton junction early bar prediction
    - Add HybridScanlineAnalyzer class with skeleton tracing, junction detection, and cross-track normal-run bar detection
    - y-min endpoint selection prevents bar from being followed as path
    - Extend ScanlineEvidence with lookahead_x/y, path_length_px, junction fields
    - Add EARLY_BAR_PREDICTED state to IShapeTurnaroundPlanner for junction-based early prediction
    - Update scanline_i_runner with --hybrid flag and hybrid field logging/overlay
2026-07-25 feat: complete HybridScanlineAnalyzer integration with tests and web adapter
    - Add _row_run to HybridScanlineAnalyzer (was missing)
    - Update scanline_i_route.py web adapter with use_hybrid config and hybrid overlay
    - Add 8 tests for HybridScanlineAnalyzer: junction detection, arm count, stem endpoint selection, EARLY_BAR_PREDICTED transitions, false alarm recovery, legacy compatibility
    - Update runner draw/log payload with hybrid fields
2026-07-25 feat: show Arduino drive motor output on dashboard
2026-07-25 feat: brake I turn on calibrated red marker exit
2026-07-25 revert: restore green-white detector before floor filter
2026-07-25 ui: move scanline debug panel to frame top
2026-07-25 feat: align tape roi display and calibrate red band layers
2026-07-25 Fix live scanline tuning and add structured telemetry (#1)
    * fix: use confirmed bar position for I-turn braking
    * feat: recognize split red bands on green white I turns
    * feat: brake I turn on calibrated red marker exit
    * feat: add isolated four-endpoint pivot planner
    * feat: expose four-endpoint pivot validation on web
    * fix: wait for passed bar before four-endpoint pivot
    * fix: stop four-endpoint route after missed red exit
    * fix: finish four-endpoint pivot on skeleton reacquire
    * fix: reject pale floor from green white route mask
    * fix: recover fisheye widened green-white route
    * fix: restore permissive green-white route detection
    * revert: restore green-white detector before f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
    [app.py]
2026-07-25 chore: remove unused red warning slow pwm
2026-07-25 fix: log pc adaptor worker tracebacks
2026-07-25 fix: cap pc adaptor differential pwm
2026-07-25 feat: calibrate keyboard turns against red line
2026-07-26 feat: add isolated Haar face sensitivity probe
2026-07-26 fix: bundle Haar cascade for Pi face probe
2026-07-26 feat: add dual camera face preview
2026-07-26 feat: face-offset triggers in-place LEFT_90/RIGHT_90 pivots via Pi API
    - PC analyses Pi video_feed for face offset
    - Auto-toggles M gate on first turn
    - Deadband + cooldown prevent oscillation
    - --no-motor flag for observation-only mode
    - phone source now optional
2026-07-26 fix: reuse Q E PWM for face centering pivot
2026-07-26 feat: increase face pivot torque
2026-07-26 refactor: split camera support modules
2026-07-26 fix: restore low-latency camera capture
    [camera.py]
2026-07-26 fix: make autonomous drive stops explicit and leased
    [controller.py]
2026-07-26 refactor: unify visual turn pulse power
2026-07-26 revert: restore separate visual turn PWM settings
    [configuration.py, tracker.py]
2026-07-26 fix: restore reliable web key controls
    [controller.py]
2026-07-26 revert: restore two-face white-line roundtrip baseline
    [controller.py, tracker.py]
2026-07-26 fix: isolate manual and autonomous drive ownership
    [controller.py]
2026-07-26 fix: use DroidCam virtual camera for face input
2026-07-26 perf: strip red detection, add green mask cache, lower process_fps
    - Remove RedEndBandDetector import and calls (no red tape on field)
    - Green mask cached: recompute every 4 frames, reuse for rest
    - green_dilate_radius_px: 22 -> 10 (kernel 45x45 -> 21x21)
    - process_fps default: 20 -> 10
    - analyse_fast_line supports cached_course_mask parameter
    - EndLineStopPlanner.step() removes red_detected parameter
2026-07-26 fix: add back _last_red_side attrs, RedEndBandObservation dummy import
    - _last_red_side, _red_alignment_min_angle, _red_alignment_confirm_frames,
    _red_alignment_streak preserved as compatibility attrs
    - RedEndBandObservation(False) dummy to satisfy overlay/log code
    - Fully working: running=True, state=PAUSED on Pi
    [tracker.py]
2026-07-26 fix: keep end-line tuning after red detector removal
    [tracker.py]
2026-07-26 fix: retry busy face camera automatically
2026-07-26 fix: freeze card motors and widen face gate
2026-07-26 fix: freeze visual turn timing and line gate
    [tracker.py]
